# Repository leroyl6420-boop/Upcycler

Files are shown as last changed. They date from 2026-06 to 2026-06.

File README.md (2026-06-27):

# Upcycler
A machine that turns plastic PET bottles into 3D printing PET filament! 

This is the biggest project I have ever worked on as a middle schooler going into high school. I started this project to reduce plastic pollution, and also to stop wasting tons of money on filament for my voracious 3D printer! I'm making it open source, so you can replicate it (without spending months of time on mistakes!) 

Pros:
- Good for the environment!
- Costs only $50!
- Fun to make!

Cons:
- Threatens to put filament companies out of business!

I hope that my repo helps you replicate my proudest achivement yet! Have fun!

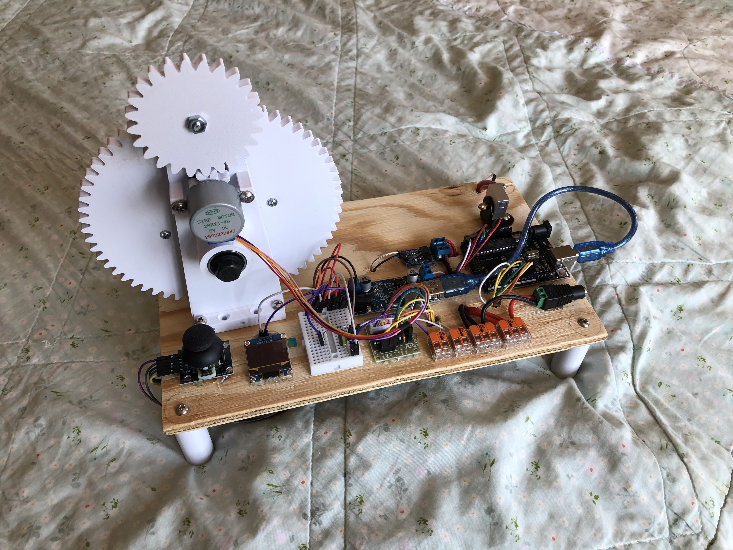
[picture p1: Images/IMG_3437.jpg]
Picture of Upcycler


The following are instructions on how to build the Upcycler yourself:

# PARTS TO PRINT

Print these parts however you like to print mechanical components! I like to print them fast with PLA (to save time and money), but print them out of CF if you want to pass your Upcycler onto your great-great grandchildren! The following prices are based of generic PLA prices.

- Main Body x1 (aprox. $0.92)
- Short Body x1 (aprox. $0.62)
- Spool Cap x1 (aprox. $.30)
- Leg x4 (aprox. $0.67)
- Big Gear x1 (aprox. $1.22)
- Small Gear x1 (aprox. $0.04)
- Driven Gear x1 (aprox. $0.23)
- Driver Gear x1 (aprox. $0.07)
- Spool Body x1 (aprox. $0.96)

# Physical Components

These are the parts you might have lying around if you have a 3D printer, or that you may find at Home Depot or Lowe's. Keep in mind that the prices are based off bulk prices I found in those stores. However, most of the pieces are very general-use (like the #6-32 and #8-32 screws) so I'm sure you'll find good use for them ;) 

- Base (cut a 0.3in thick piece of plywood into a 12in x 7in board) x1 (aprox. $1.80)
- Metal L-Bracket (make sure that the diameter of the holes are 6mm, not 5mm) x1 (aprox. $0.23)
- CR-10 Heat Block x1 (aprox $1.25)
- 1/16in Nozzle (use drill and 1/16in attachment to make your own out of any size) x1 (aprox. $0.50)
- #8-32 1.5in Screw x1 (aprox. $0.27)
- #8-32 1in Screw x4 (aprox. $0.40)
- #8-32 0.75in Screw x7 (aprox. $0.63)
- #6-32 1in Screw x8 (aprox. $0.64)
- #8-32 Hex Nut x5 (aprox. $0.45)
- 608 2RS Bearing x7 (aprox. $2.10)
- M8-1.25 60mm Half-Thread Screw x2 (aprox. $2.00)
- M8-1.25 Hex Nut x4 (aprox. $0.72)

# Electronic Components

Oh boy! These aren't parts you'd find walking around your local Micro Center! You may purchase them off your favorite online electronic retailer if you'd like, but if you prefer faster shipping (like me!), all these parts are available on Amazon! (Which is also what their prices are based on).

- ULN2003 x1 (comes with most 28BYJ-48 Stepper Motors)
- 28BYJ-48 Stepper Motor x1 (aprox. $3.00)
- Joystick (any cheap KY-023 clone will work fine) x1 (aprox. $1.67)
- 128x64 OLED x1 (aprox. $2.70)
- 12V 40W Ceramic Heater (get one that's meant for Creality Ender 3 printers) x1 (aprox. $1.40)
- Thermistor (get one that's meant for Creality Ender 3 printers) x1 (aprox. $0.80) 
- 12V-5V Buck Converter (I bought the B0FJM8XTSD, but any such converter that can handle 5A should work) x1 (aprox. $3.50)
- USB Type B (for Arduino Unos) x1 (comes with most Arduino Uno R3's)
- Arduino Uno R3 (I wouldn't buy the real thing, just buy a cheaper clone) x1 (aprox. $7.00)
- 2-Way WAGO x2 (aprox. $0.68)
- 3-Way WAGO x2 (aprox. $0.86)
- Small Breadboad x1 (aprox. $1.00)
- 50V 1uf Capacitor x1 (aprox. $0.40)
- 100k ohm Resistor x1 (aprox. $0.06)
- MTSD001 MOSFET Module x1 (aprox. $1.34)
- 12V 5A Power Supply (buy one that feeds through a jack, and make sure it comes with a female port to plug into that feeds wire connectors) x1 (aprox. $8.00)
- 16 AWG Wire (unspecified amount and cost)
- 22/24 AWG Jumper Wires (unspecified amount and cost)

All parts should run you about $48.43, pre-taxes. 

# Assembly Instructions

Now is the time to put everything together! I'll just go over the order in which you do things, and for attaching all electronic components to the base, just use hot glue and the general layout shown in the picture above.

- Drill 3/16in holes on each of the four corners of the base for the legs
- Screw legs in using #8-32 0.75in screws
- Insert all 7 bearings into all 7 bearing slots
- Insert M8-1.25 60mm screw into the main body's stud bearings: the cap should be on the protruding side
- Use M8-1.25 hex nut to secure said screw in place
- Screw Big Gear onto M8 screw
- Screw another M8 nut onto M8 screw to secure Big Gear in place
- Insert M8-1.25 60mm screw into short body's stud bearings (again, cap should be on protruding side)
- Use M8-1.25 hex nut to secure said screw in place
- Screw Spool Cap onto M8-1.25 screw
- Use M8-1.25 hex nut to secure Spool Cap in place
- Use four #6-32 screws to secure spool body onto the Big Gear
- Secure the Spool Cap (along with the short body) onto the other end of the spool body (using the other four #6-32 screws)
- Screw 2 #8-32 1in screws into the two outermost slots of each body's base
- Drill 4 3/16in holes into the base (two for the main body, two for the short body)
- Slide the two bodies into their slots, and on the belly side of the base, use four #8-32 nuts to secure the screws in place
- Drill a 3/16in hole for the L-Bracket
- Use a #8-32 0.75in screw and #8-32 hex nut to secure the L-Bracket on its hole
- Use the 1/16in nozzle to attach the CR-10 heat block onto the L-Bracket
- Secure the thermistor and the ceramic heater into the CR-10 Heat Block
- Use the USB type B to connect the 12V-5V Buck Converter's USB to the Arduino Uno's big port
- Use two #8-32 0.75in screws to secure the 28BYJ-48 stepper motor onto the main body (with its driver gear attachment attaced)
- Insert the small gear and the driven gear, back to back, into the main body's upper bearing slots. The driven gear goes on the protrusion side, and the small gear goes on the Big Gear side. Use the #8-32 1.5in screw (with a nut) to secure them tightly together, such that they can't spin independently. 

# Wiring Instructions

Alright, now is the time to really lock in. Read all the instructions carefully, because one mess-up WILL fry all your components faster than wanton wrappers in hot oil!

- Connect Arduino 5V and Arduino GND to a 5V and GND rail on the breadboard (duh). Then go ahead and connect all the Vcc's and GND's. You can't possibly screw that up. No components use 3.3V, and expand the rails if need be.
- Joystick VRx goes to Arduino A3
- Joystick VRy goes to Arduino A2
- Joystick SW goes to Arduino D4
- 128x64 OLED SCL goes to Arduino A5
- 128x64 OLED SDA goes to Arduino A4
- Connect each end of the thermistor to one of the two-way WAGO connectors. Then insert a jumper wire with a male end and a bare end into the other slot (for each). Of course, the bare end goes in the WAGO. One of the jumper wires goes straight to GND. The other one goes to its own rail. It will the called the thermistor rail.
- The 50V 1uf capacitor connects the thermistor rail and GND.
- The 100k ohm resistor connects the thermistor rail and the 5V rail.
- A jumper wire connects the thermistor rail and A0.
- Moving on from the thermistor, IN1-4 on the ULN2003 go to Arduino D11-8, respectively.
- MOSFET TRIG/PWM goes to Arduino D5. You may need to solder this connection.
- Use the two 3-way WAGOs and 12V 5A rails. One slot connects the rail to the 12V 5A power supply's wire slot attachment, the other connects the rail to the 12V-5V Buck Converter, and the last slot connects the rail to the MOSFET module. You should be able to figure out + and - in and out, as long as you have more than two brain cells.
- Connect the 12V 40W ceramic heater to MOSFET out(s). 

You have successfully built your very own Upcycler! Feed it 7mm PET plastic strips (around 0.4mm thick) and it'll give you filament to your heart's content!

AI use: I used ChatGPT in PREVIOUS VERSIONS of the Upcycler (versions 1 and 2) to code the Arduino, as I was less experienced in coding then. However, after attending Horizons Nexus (which was really fun!) I learned a lot more skillz and I coded the Upcycler V3 by myself! Well, I was already familiar with the GPT generated code, and I can't say that I didn't use some ideas from there, but I didn't copy/paste anything and you could basically call it learning at this point ;) anyway I don't think it counts as AI use.

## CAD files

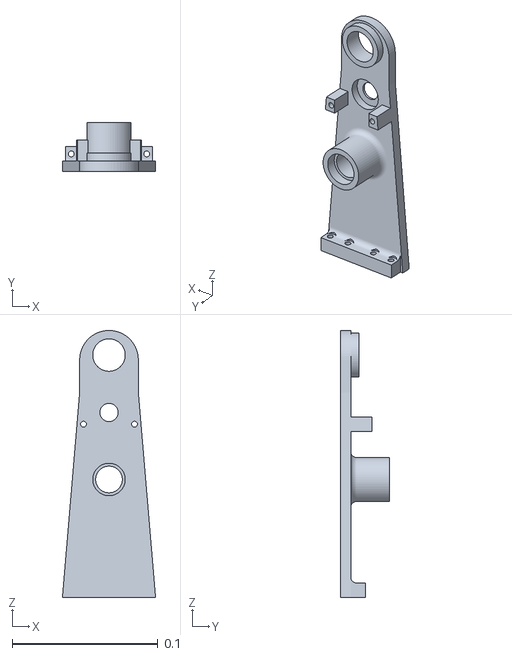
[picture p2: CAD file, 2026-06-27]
Parts to Print/Full Main Body (1).stl
0.064 x 0.0335 x 0.183

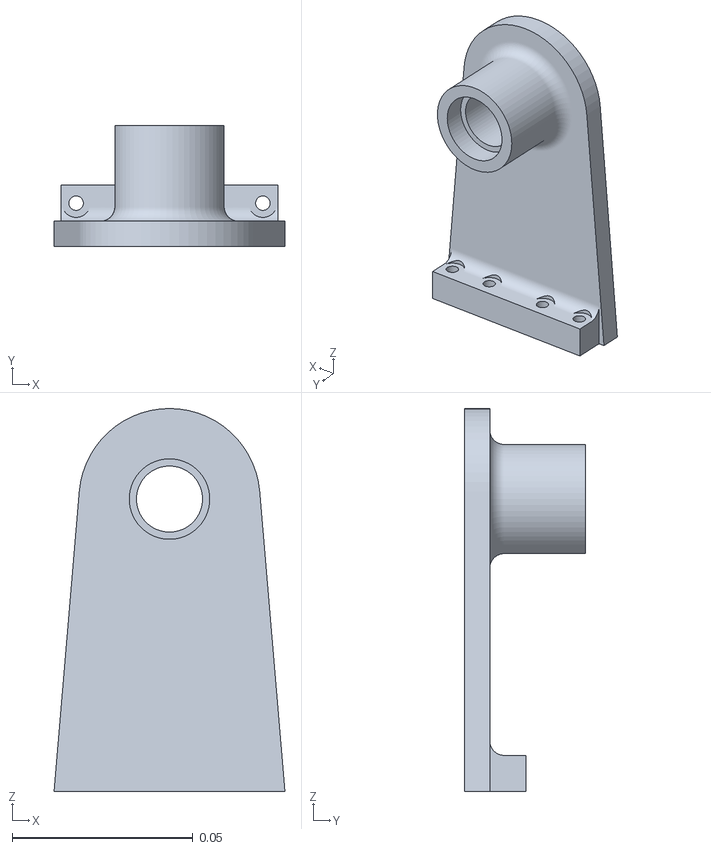
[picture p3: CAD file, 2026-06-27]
Parts to Print/Full Short Body (1).stl
0.064 x 0.0335 x 0.106

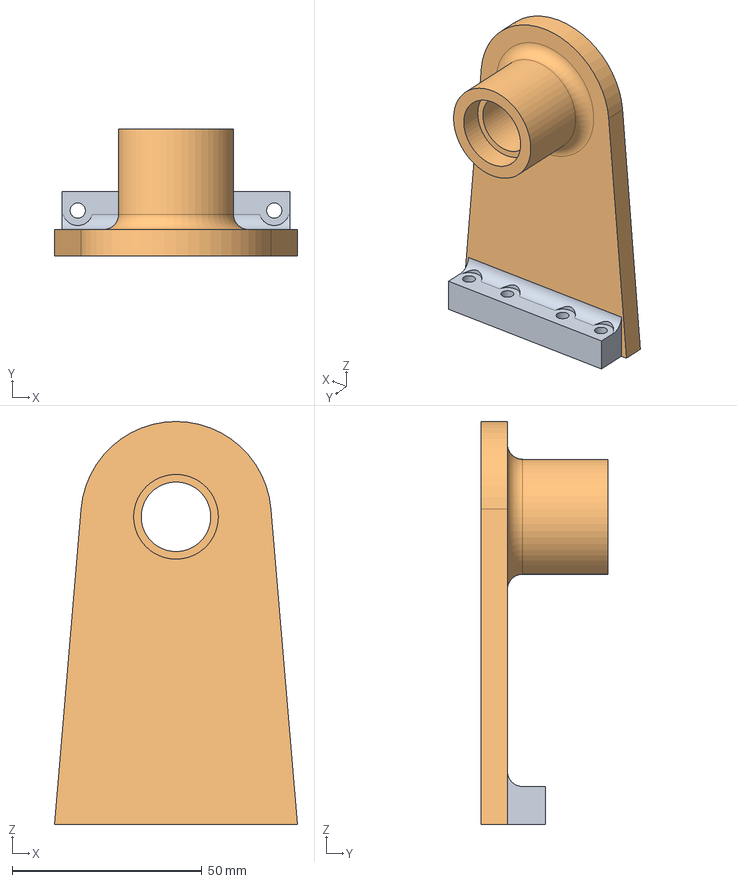
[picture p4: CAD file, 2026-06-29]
STEP Files/Full Short Body.step
64.0 x 33.5 x 106.1 mm
V2

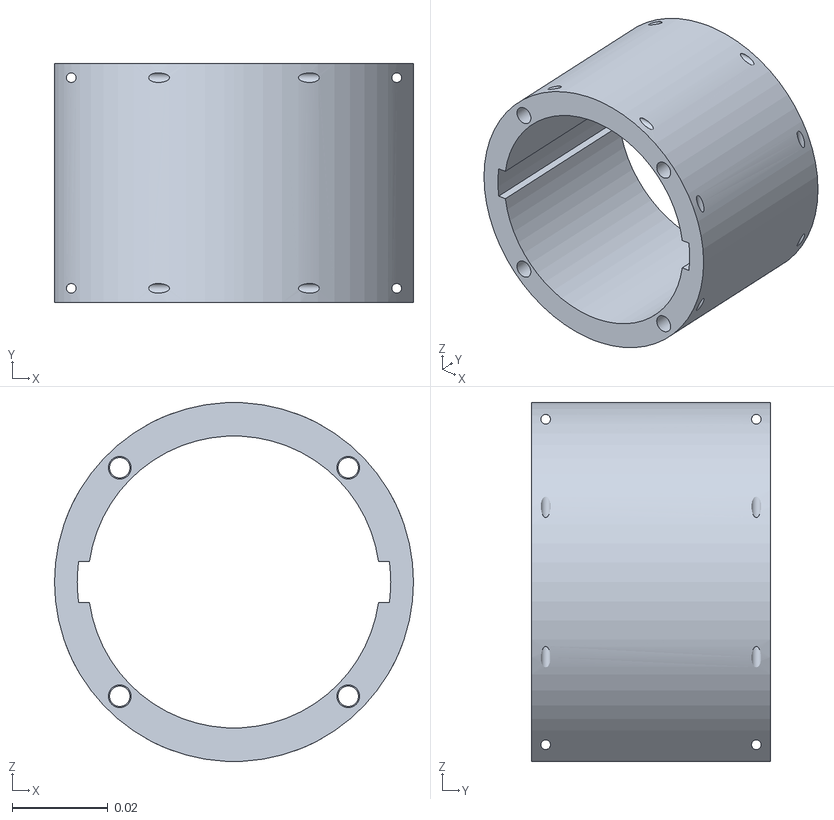
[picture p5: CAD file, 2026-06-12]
Parts to Print/PullerAssembly-SpoolSpoolBase (1) (3).stl
0.075 x 0.05 x 0.075

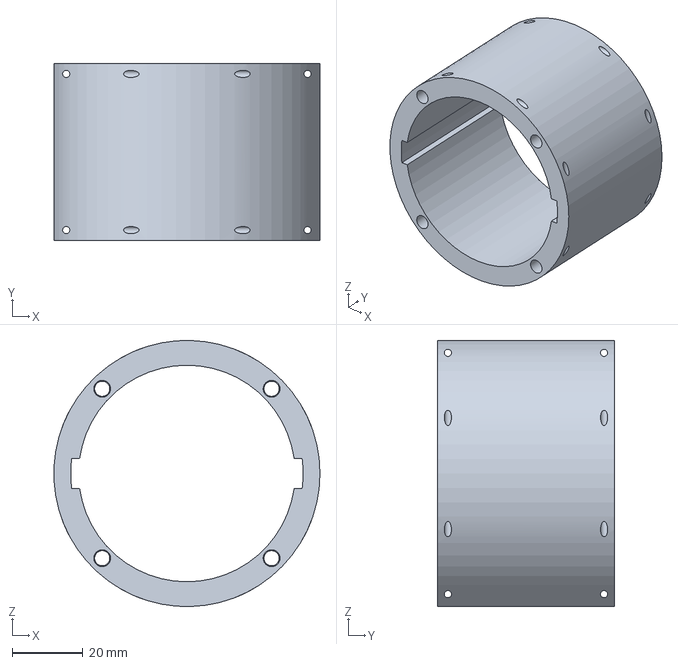
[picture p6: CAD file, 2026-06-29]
STEP Files/PullerAssembly-SpoolSpoolBase (1) (1).step
74.9 x 50.0 x 75.0 mm

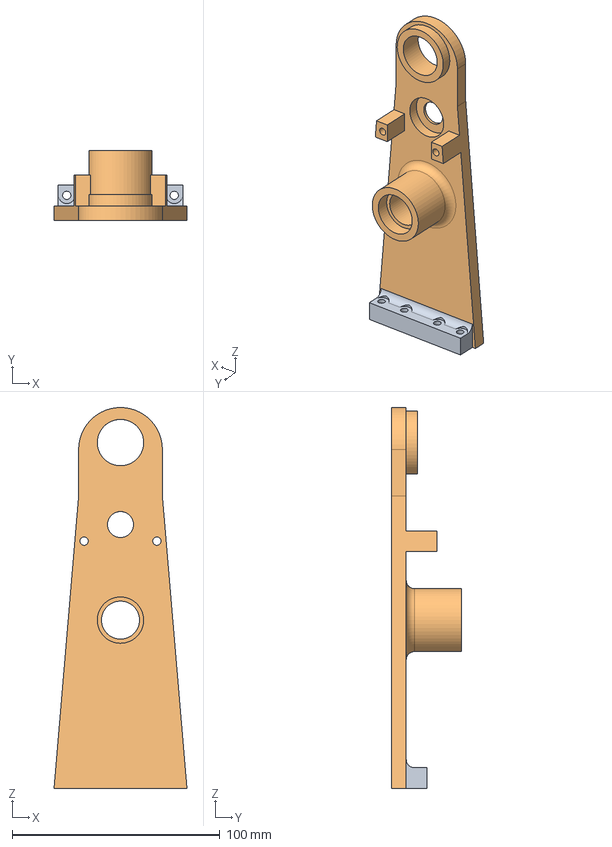
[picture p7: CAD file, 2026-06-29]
STEP Files/Full Main Body.step
64.0 x 33.5 x 183.3 mm
V2

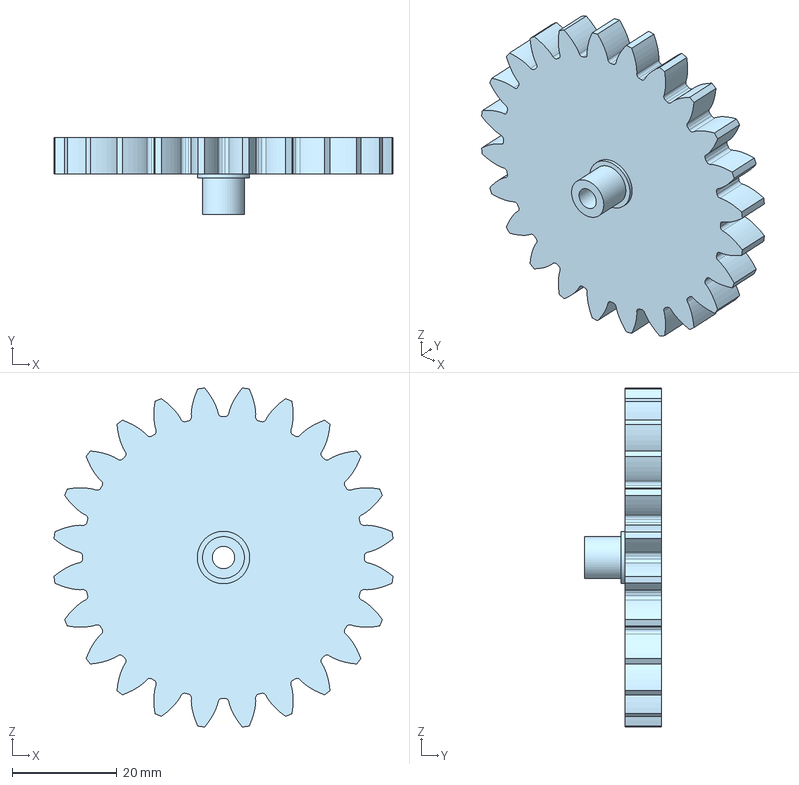
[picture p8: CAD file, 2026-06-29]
STEP Files/Driven Gear.step
64.6 x 14.7 x 64.6 mm

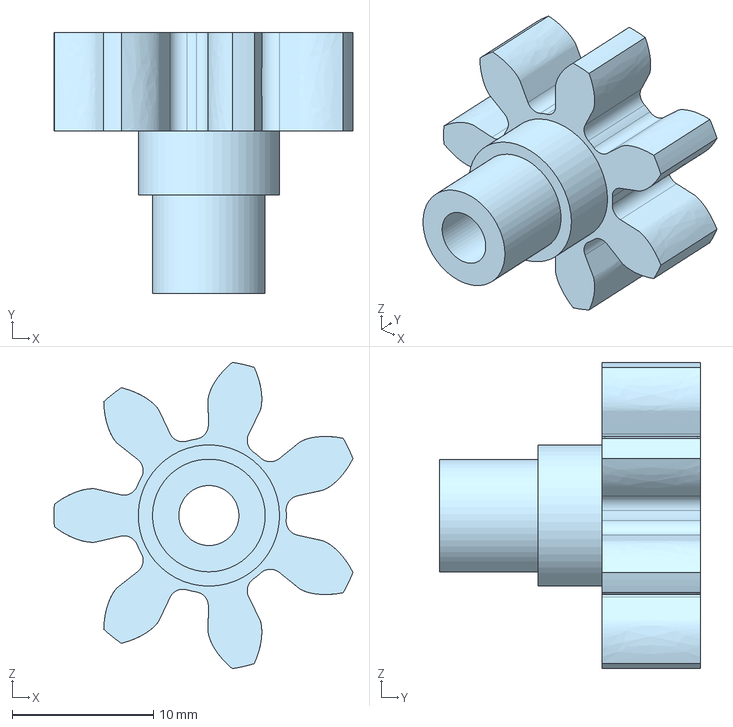
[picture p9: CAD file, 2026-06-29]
STEP Files/Small Gear.step
21.2 x 18.5 x 21.7 mm

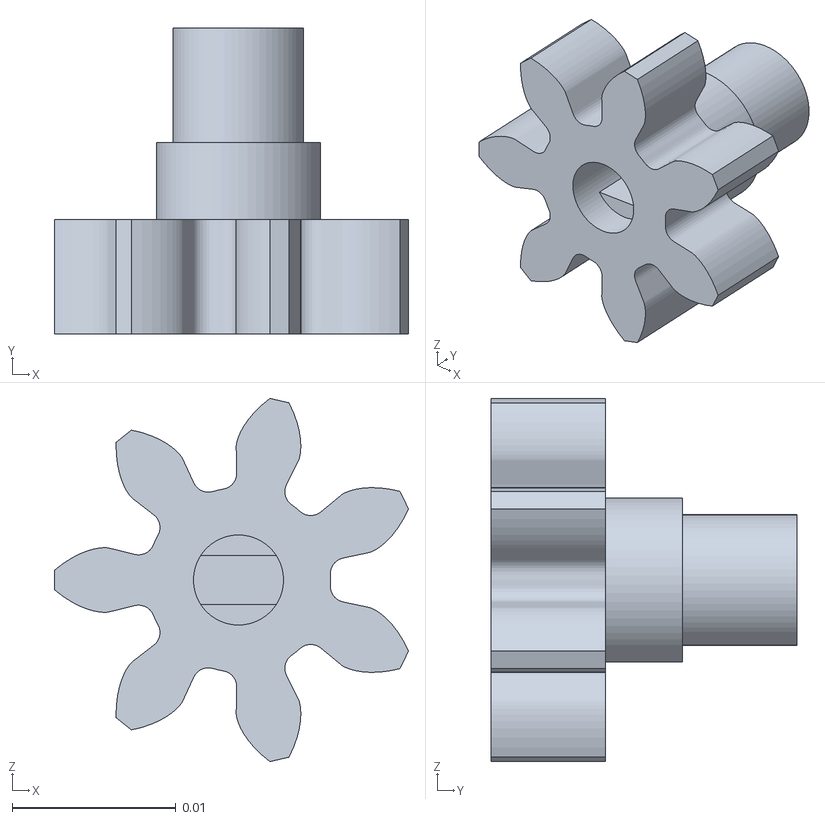
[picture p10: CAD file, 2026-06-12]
Parts to Print/Driver Gear (2).stl
0.0216 x 0.0187 x 0.0222

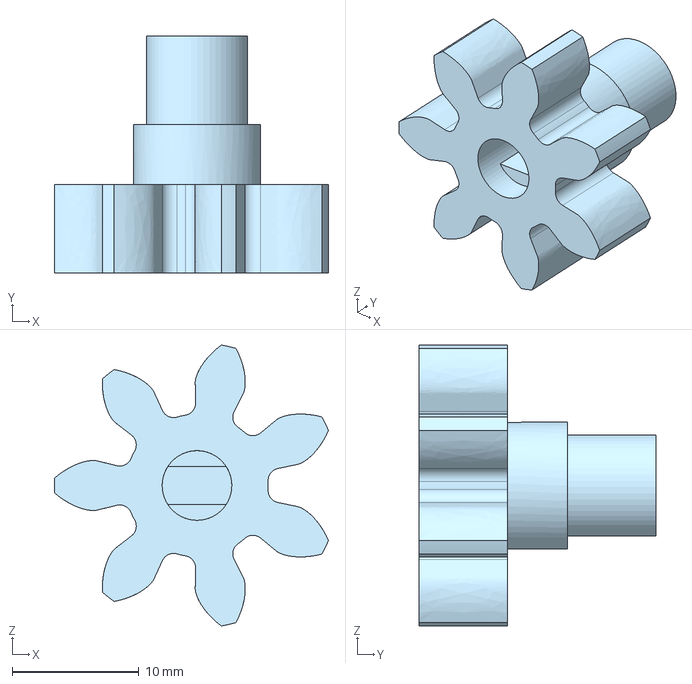
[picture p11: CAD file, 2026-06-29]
STEP Files/Driver Gear.step
21.6 x 18.7 x 22.2 mm

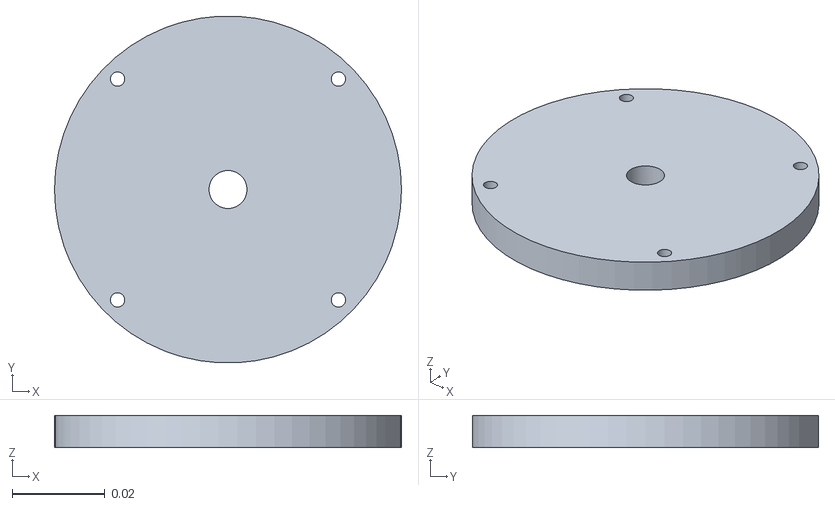
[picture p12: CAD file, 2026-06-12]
Parts to Print/Spool Cap.stl
0.075 x 0.0749 x 0.007

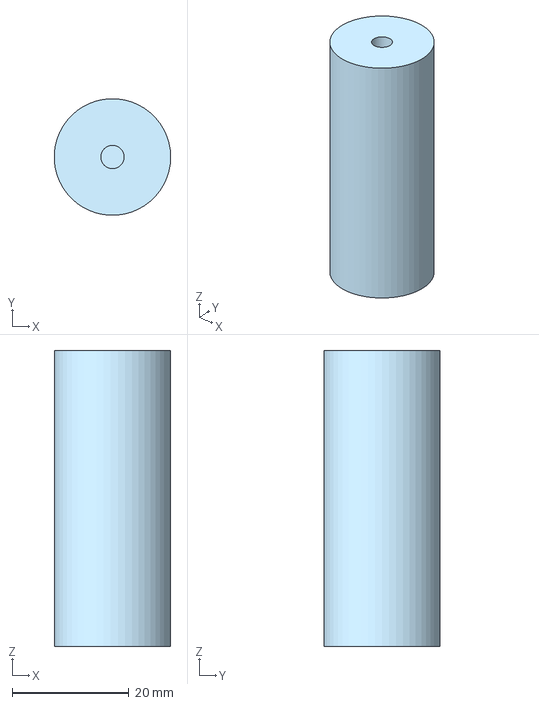
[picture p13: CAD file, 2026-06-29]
STEP Files/Leg.step
20.0 x 20.0 x 50.8 mm

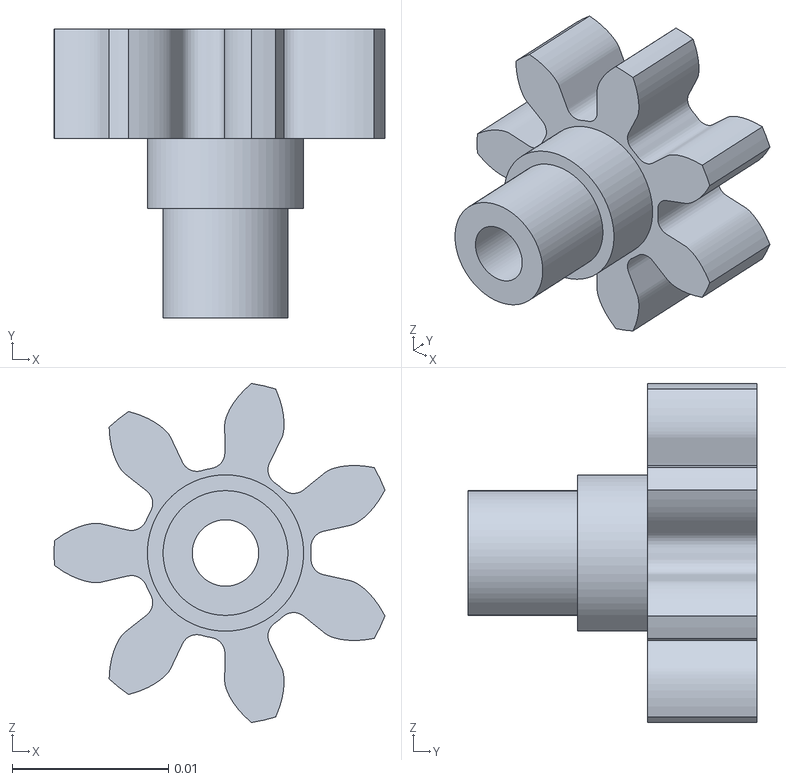
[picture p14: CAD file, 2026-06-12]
Parts to Print/Small Gear (6).stl
0.0212 x 0.0185 x 0.0217

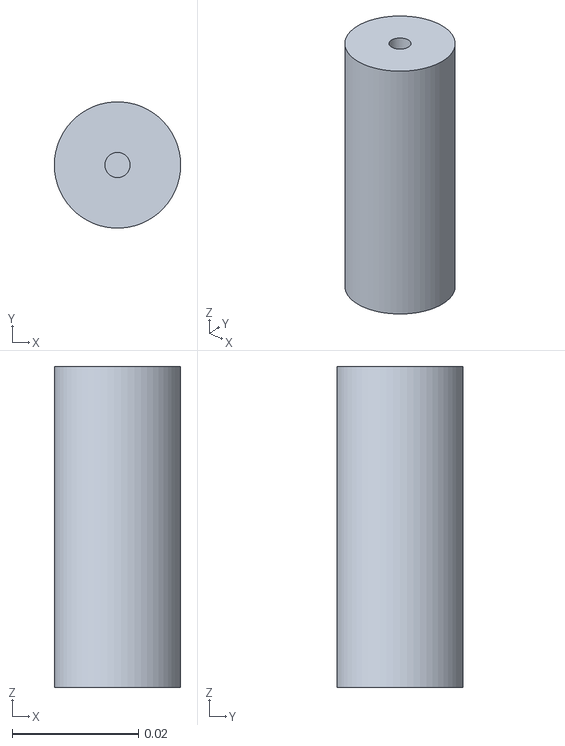
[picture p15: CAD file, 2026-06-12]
Parts to Print/Leg (1).stl
0.02 x 0.02 x 0.0508

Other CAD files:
Parts to Print/Big Gear (8).stl
STEP Files/Big Gear Inner Ring.step
Parts to Print/Driven Gear (2).stl
STEP Files/Big Gear.step

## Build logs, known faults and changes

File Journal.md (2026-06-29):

# Devlogs

Hi! Welcome to my project journal! Before you take a peek, you may realize that the commits do not match the logs. That is because this is literally my first time using Github and I didn't really know how to do a journal for devlogs until I was gonna ship :P
If you're a reviewer reviewing my project and you really need proof of the devlogs, I wrote quick summaries under each of my timelapses in Lapse, which is also what my devlogs will be based on. If you need anything from me to clear things up, please let me know in any way. I check Slack very often. Sorry for the inconvenience! Thank you for all your hard work :)

NOTE: If you are checking my project out from Stardance, the reason why I have this Journal.md is because this project was started in Horizons. I had to keep my devlogs here because there was no devlog feature on the website. I stopped updating this journal when I moved over to Stardance, and I wrote the rest of my devlogs there. Thanks for the understanding!

# Devlog 1
1h 0min 27sec Logged

I started working on my Upcycler project today! I need to make a full 3D model as a plan, so I found some files online of a motorized mechanism that pulls the PET in a PET puller. I imported them into my project, but I discovered that they need 608 2RS bearings, M8-1.25 60mm screws, and M8-1.25 hex nuts to be fully put together. I found the dimensions of those parts online and modeled them myself! Afterwards, I brought all the part studios into an assembly and put together the first model of the body (you can find models in branch First-CADS). However, I still need to greatly adapt the puller mechanism to use 28BYJ-48 stepper motors instead of expensive 12V 3RPM DC motors. I started that today by calculating the grams of force per centimeter sqaured of each motor. My motor was approximately 20x weaker than theirs. To compensate for friction, bending of the materials, and the fact that the spool's axle has only one attachment point, I estimated the need for a 30:1 ratio. I modeled the driven gear as large as I could, but my math still does not see my mechansim working. I'll need to improvise a geartrain for everything to work. 

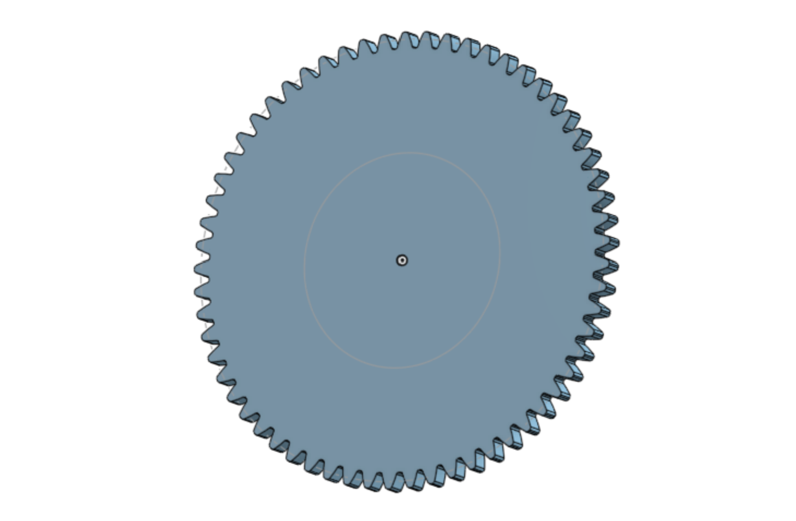
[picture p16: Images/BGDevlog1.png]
Picture of Big Gear

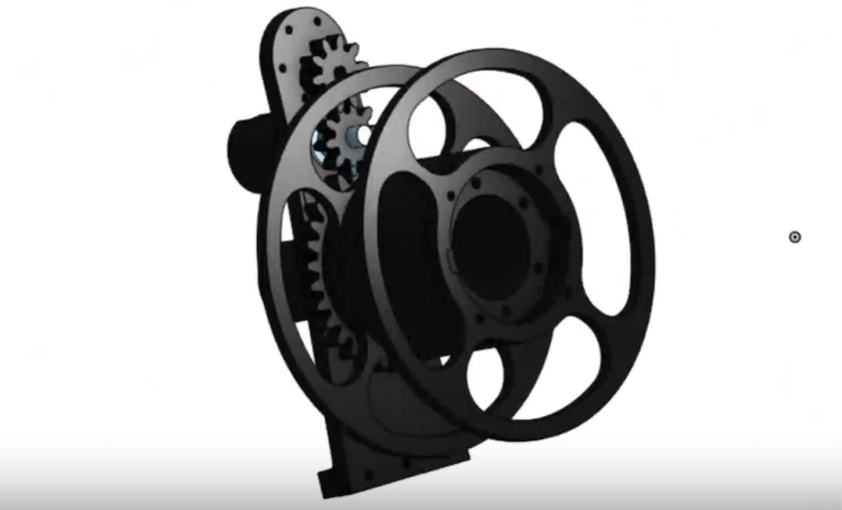
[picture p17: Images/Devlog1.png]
Picture of Upcycler
 

# Devlog 2
1h 1min 12sec Logged

I worked on the geartrain for my Upcycler! I finished modeling the big gear to fit the spool and the axle, and I'm getting started on the other gears. I've decided to incorporate four gears: the driver gear will be connected to the 28BYJ-48 stepper motor, the driven gear will be above that (at a 24:7 ratio), and the driven gear will be on the same axle the small gear, which will drive the big gear (at a 61:7 ratio). That should result it a roughly 30:1 ratio. Of course, to fit the new axles and gears, I had to change the body of the puller a lot. I removed the mounting holes meant for the original motor, and I made new slots for new bearings. You can find the files in the 2nd-CADs branch.

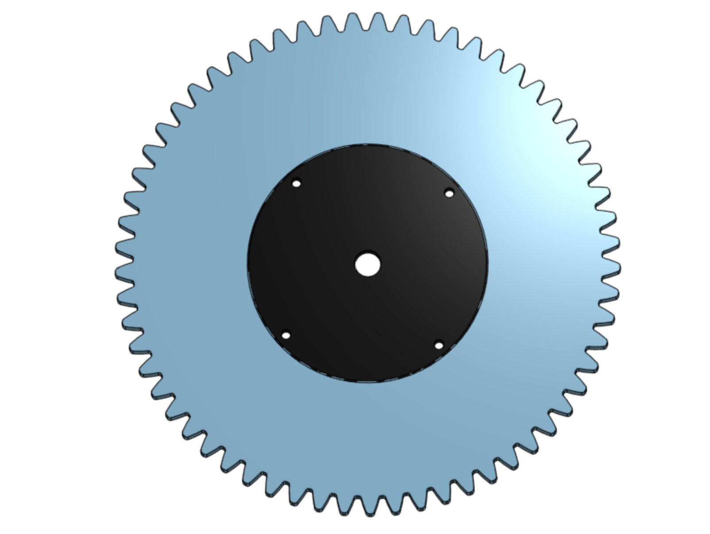
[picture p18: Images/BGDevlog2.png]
Another Picture of Big Gear
 
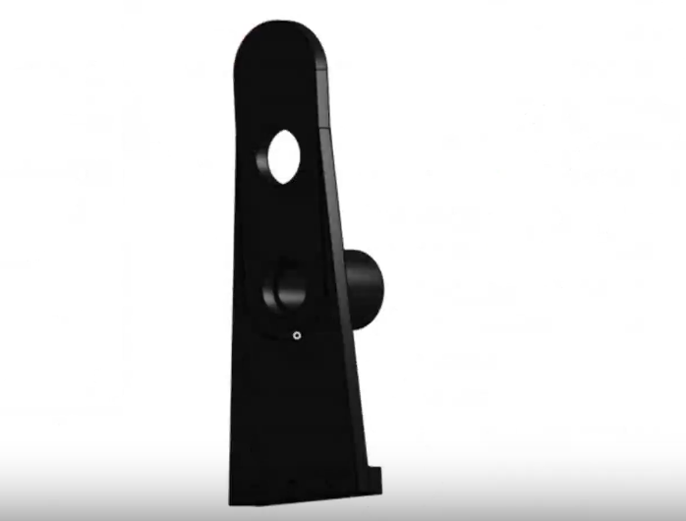
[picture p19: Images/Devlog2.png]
Second Picture of Upcycler
 

# Devlog 3
1h 4min 57sec Logged

I finished adapting the body of the puller! I added all the necessary bearing slots, I added attachment points for the 28BYJ-48 stepper, and I trimmed a bit off the stud to save filament, save time, and make installment easier. I modeled all three other gears, and I'll put the assembly together soon. however, I decided that I wanted two attachment points for the spool's axle. First, I had to make the other end of the spool capable of taking an axle. I modeled a spool cap by using the same inner ring I used for the big gear. I will be able to add that to the other end of the printed spool. That means I'll need to model a shorter body next, as the second attachment point doesn't need a motor and geartrain, but it does need support. 

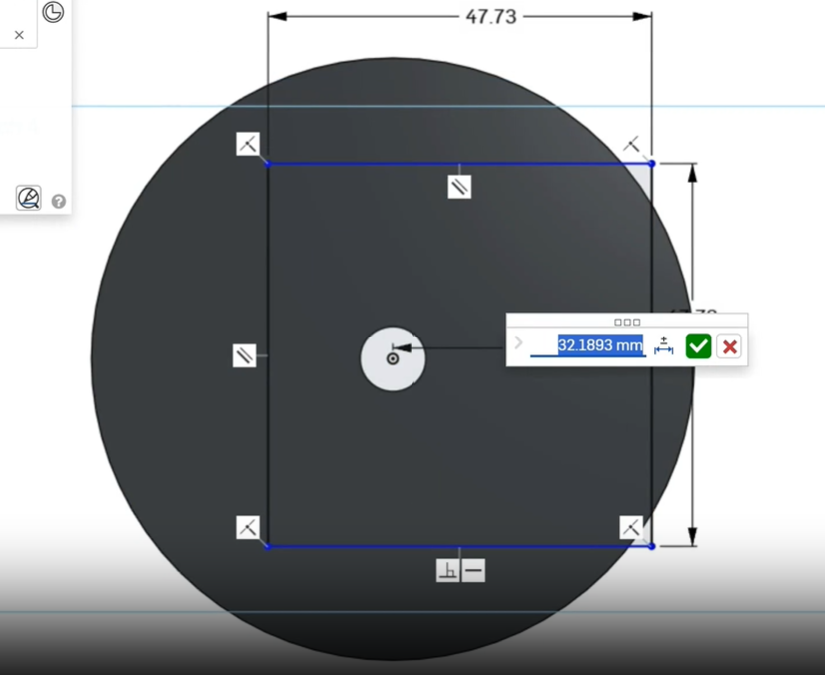
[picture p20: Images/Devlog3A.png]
Picture of Spool Cap

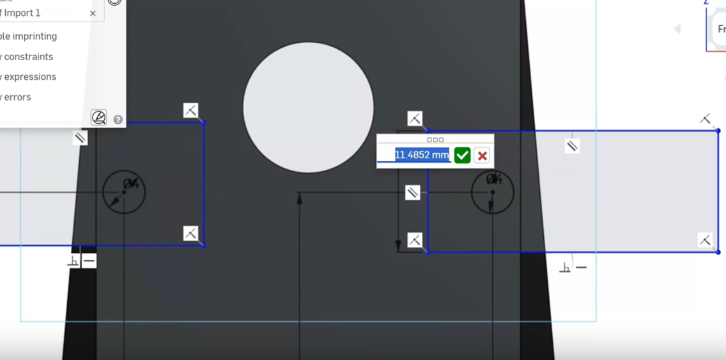
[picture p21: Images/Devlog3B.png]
Picture of adapted body


# Devlog 4
1h 7min 10sec Logged

First, I modeled the short body. I basically just copied the normal body and cut off the top. I used a circle centered on the axle and tangent to the body's sides to mark the roof. Afterwards, I modeled the legs of the Upcycler. I had to match dimensions I estimated in real life. I'm planning to secure them to the wooden base using #8-32 screws. Finally, I started putting everything together in the assembly again. So much has changed since I did this the first time! I had to redo a bunch of stuff. Everything fits perfectly, as per my calculations! I need to move on to modeling the rest of the Upcycler next: the puller is just one of the biggest parts. You can find the CAD files in the 3rd-CADs branch. 

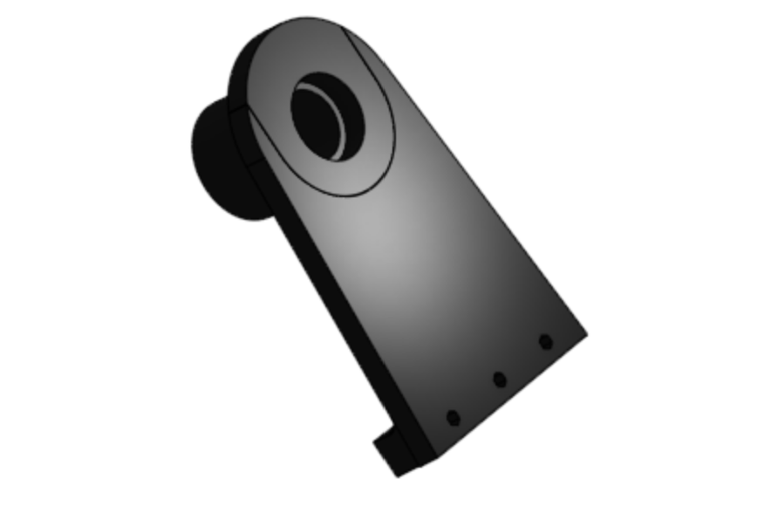
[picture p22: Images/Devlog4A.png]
Picture of short body

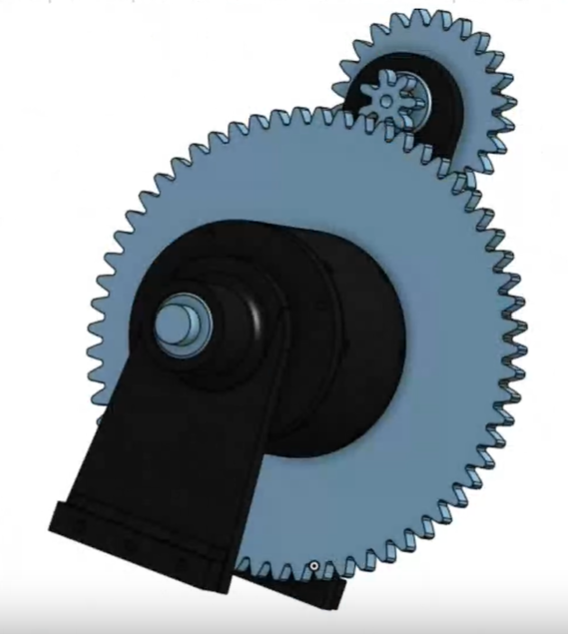
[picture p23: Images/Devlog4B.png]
Picture of Devlog 4 Assembly


# Devlog 5
1h 2min 49sec Logged

I grinded out models of all the screws that I'll be using! I couldn't find any #8-32 screw models online that were in parasolid format, so I decided to model them myself! I modeled the #8-32 1.5in, 1in, and 0.75in screws. I also modeled a 1in #6-32 screw. I added them all to the assembly and put them all in place! Afterwards, I added the base to the assembly and added holes to it for the #8-32 screws to secure the legs. Things are really coming together!

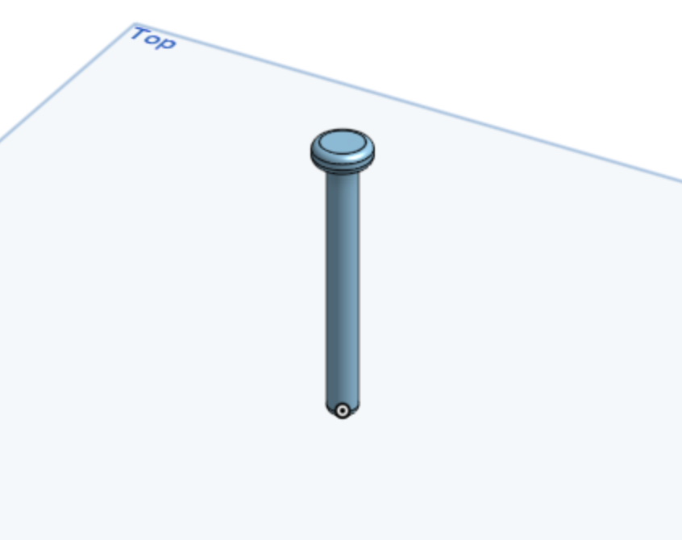
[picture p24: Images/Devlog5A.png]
Picture of #8-32 1.5in screw model

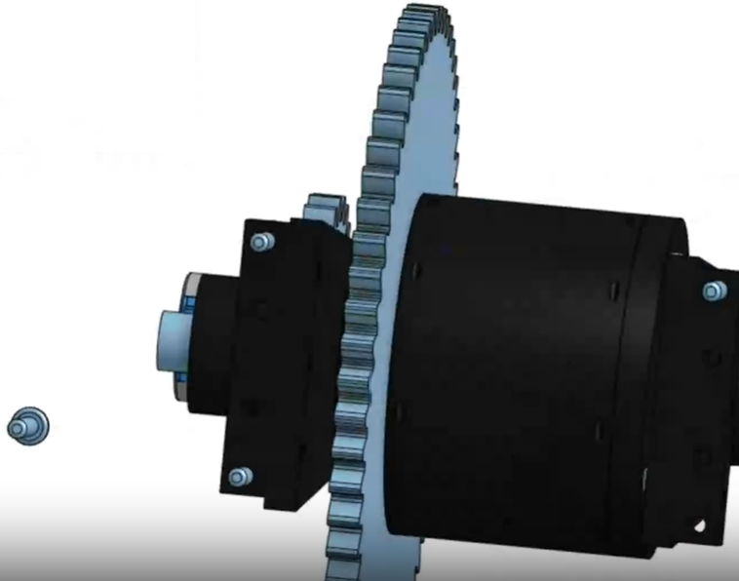
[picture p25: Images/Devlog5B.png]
Picture of assembly with screws


# Devlog 6
1h 4min 45sec Logged

I added more holes to the base for attaching the puller. The plan is to make the holes around 3/16in wide in diameter in real life, larger than the #8-32 1in screws' diameters, so that there will be room for error while drilling. Then, the screws (and the bodies they wil be securing) will be secured using #8-32 hex nuts. I added the legs to the assembly and attached them to the base as planned. Finally, I found 3D models of a few of the electrical components I used online and added them to the assembly. I don't like them very much, as they are not parasoilds that Onshape can render easily, but I suppose they'll do for now. I think I'll just make my own models in the future. 

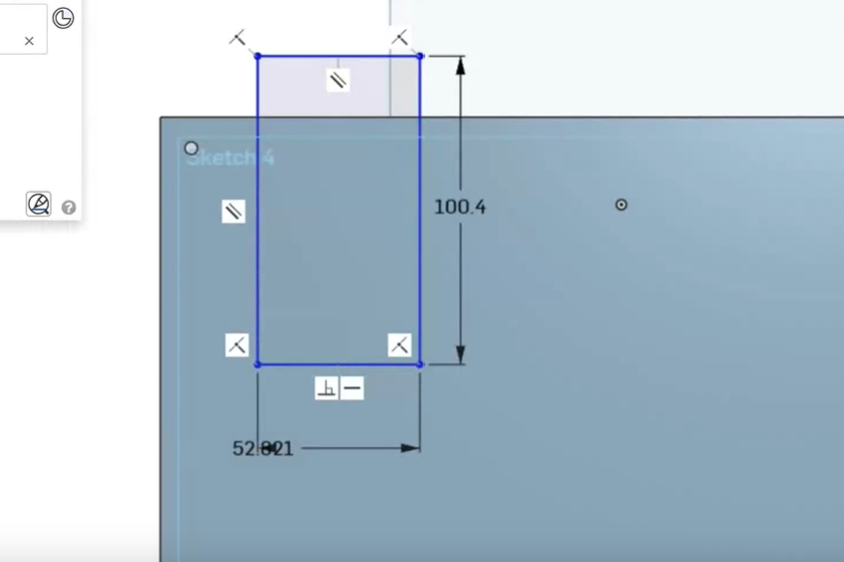
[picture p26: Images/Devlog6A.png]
A picture of adding holes to the base

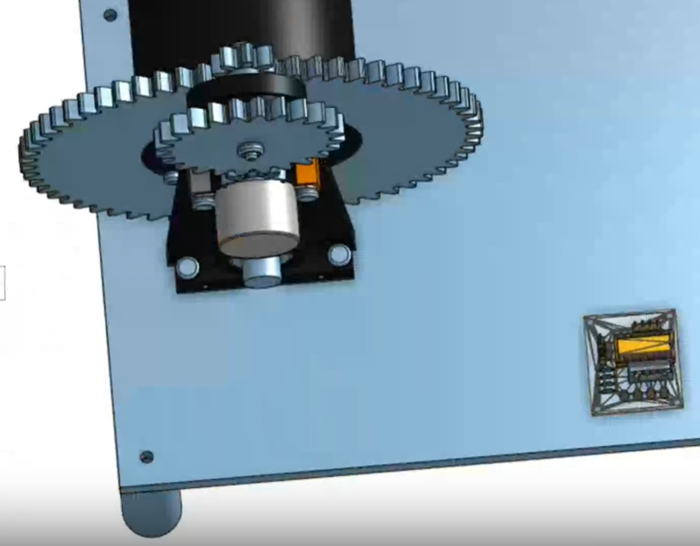
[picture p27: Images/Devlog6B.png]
A picture of the assembly with legs and an imported ULN2003 model


# Devlog 7
1h 0min 22sec Logged 

I found more files for more of the electronics I used online. One of them, the breadboard, was able to be rendered by Onshape, and it looks fine. The other, the OLED, was not able to be rendered by Onshape, and it is another janky-looking part. I still added them to the assembly. I wanted to add the WAGOs next, but I also wanted to avoid weird files, so I modeled the WAGOs myself. I found the dimensions online and even added fillets to make them look more realistic. I think that I'm pretty good at that, so I think I'll model more parts. In the meantime, the assembly is looking more and more complete every Devlog! You can find the files in the 4th-CADs branch. 

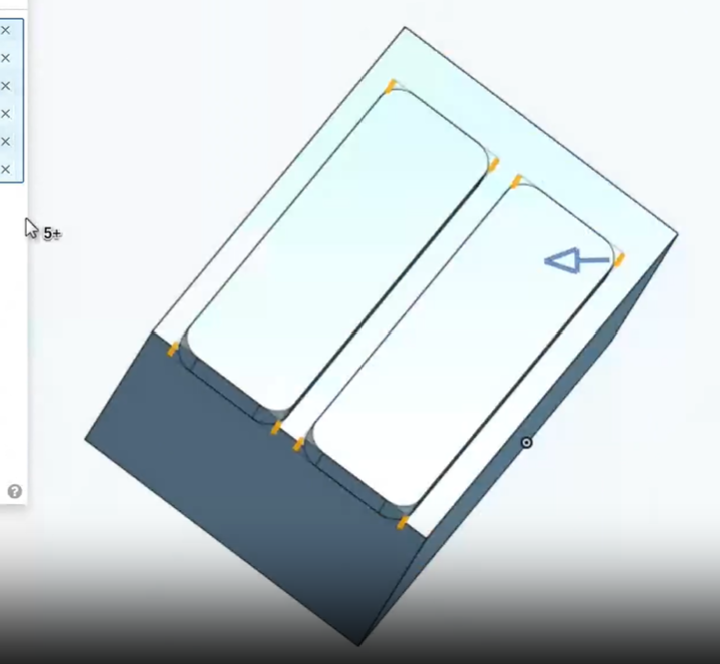
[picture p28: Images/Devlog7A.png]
A picture of a 2-way WAGO I modeled

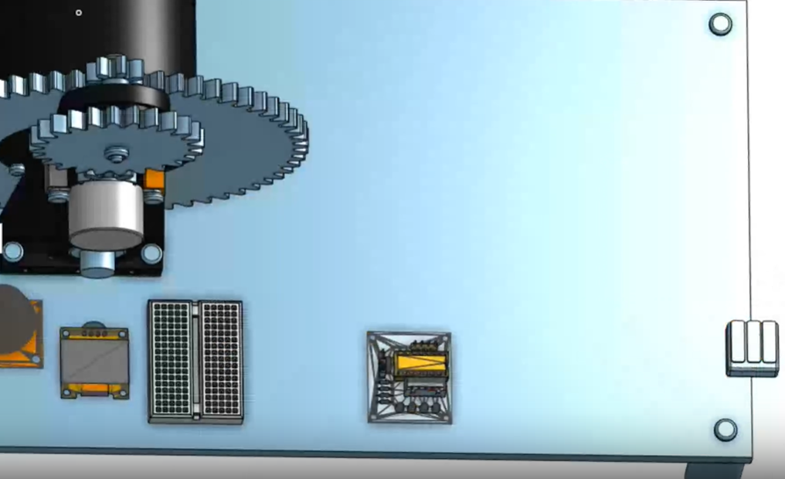
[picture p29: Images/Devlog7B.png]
A picture of the assembly with all the parts thus far


# Devlog 8
2h 53min 17sec Logged 

Oh, boy! I really locked in for this CAD session! I modeled the rest of the components, by myself!I modeled the relay, the 12V-5V buck converter, the l-bracket, the CR-10 heat block, and I turned the assembly into a simulation! The l-bracket and CR-10 heat block were easy to model, because I just had search up their dimensions online and translate that into a part studio in Onshape. The relay and 12V-5V buck converter were harder. I had them in real life, so I used a digital caliper to measure the individual parts and model them in Onshape to the best of my ability. I got details like filets and chamfers, and I added extrude removes for USB ports, wire ports, and screw ports. Afterwards, I added all the parts to the assembly, and I finished putting everything together! That wasn't it, though! To see how it would really work, I added gear relationships to the revolve mates of the gears, and I saw Onshape simulating the Upcycler running! I'm ready to build the Upcycler now!

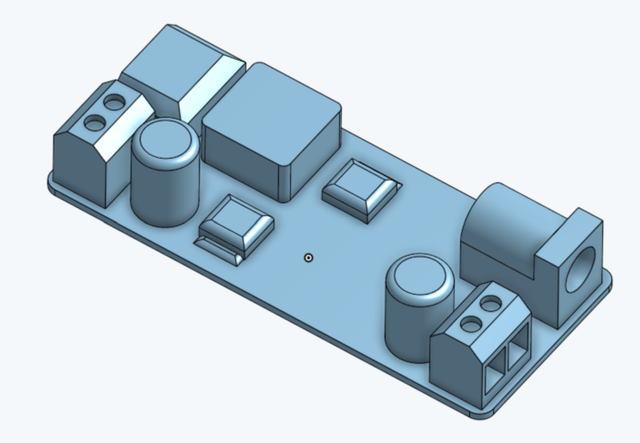
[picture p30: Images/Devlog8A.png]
A picture of the 12V-5V buck Converter

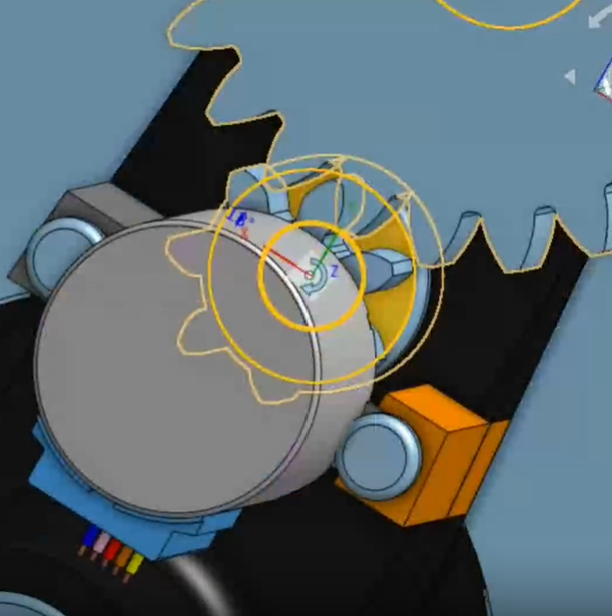
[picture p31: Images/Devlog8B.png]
A picture of adding simulation to the gears

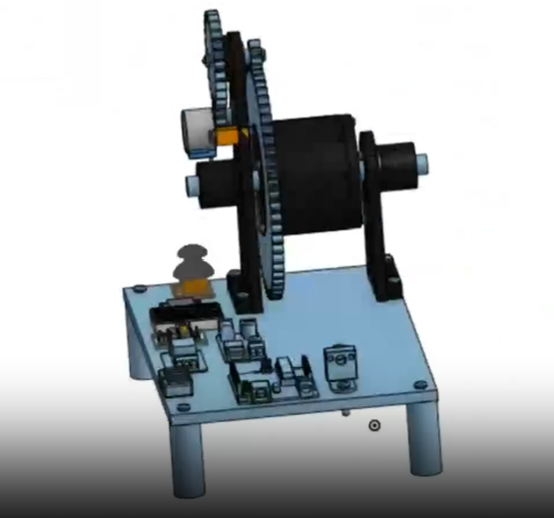
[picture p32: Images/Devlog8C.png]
A picture of the finished assembly


# Devlog 9
1h 2min 34sec Logged

This was my first building session! First, I drilled four holes at the corners of the wooden base I got to attach the legs. I had printed the legs out beforehand, so I just had to screw them on. Then, I put together the short body. I inserted the bearings, I threaded the M8-1.25 60mm screw, I screwed on a nut, I screwed on the spool cap, and I screwed on a second nut. Afterwards, I put together the axle of the main body. I repeated the same process as the short body, but I used the big gear instead of the spool cap. I then secured the spool body onto the big gear using four #6-32 1in screws. Things are going well so far!

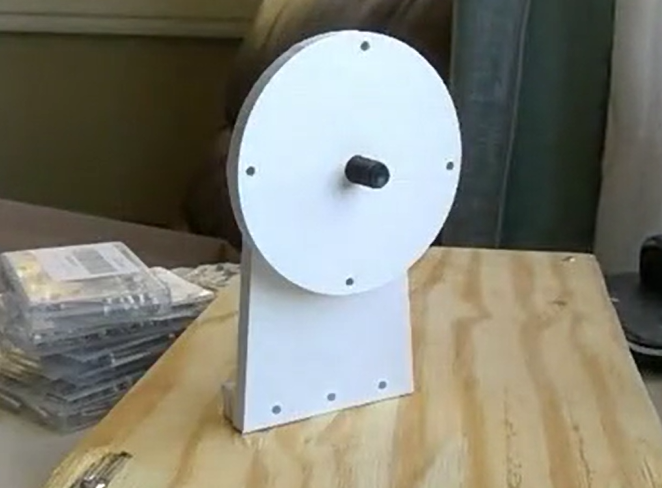
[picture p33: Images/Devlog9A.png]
A picture of the assembled short body, short of the second nut

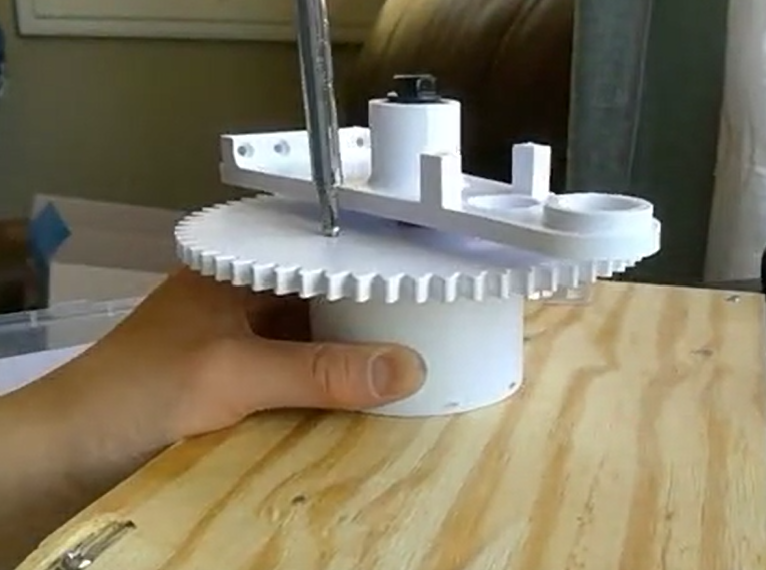
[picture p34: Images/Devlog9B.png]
A picture of securing the spool body to the big gear on the main body


# Devlog 10
1h 6min 37sec Logged

I continued building the Upcycler! I screwed the driven gear and the small gear together using a #8-32 1.5in screw, and after attaching a nut, they can no longer spin independently. However, that was before I screwed the base screws onto the body, and the driven gear got in the way of me doing that, so I had to undo my work, screw in the base screws, and put them back on again. In other news, I attached the spool cap (and the short body) onto the other side of the spool body, making our puller assembly complete! Our 28BYJ-48 stepper motor is ready to go, it just needs the electrical components now, which is what we will be working on next!

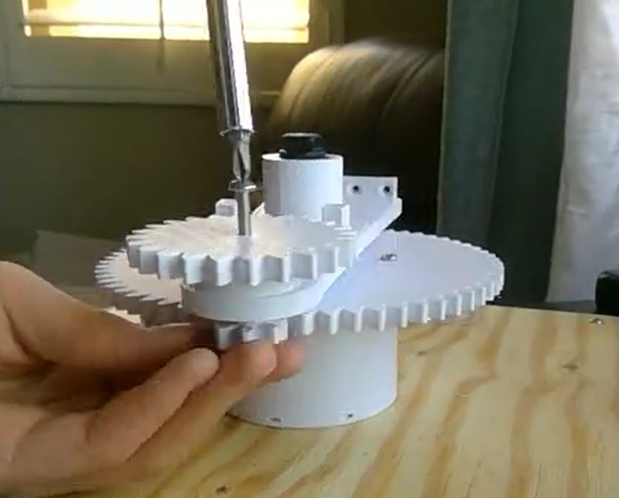
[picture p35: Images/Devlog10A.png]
A picture of me joining the driven gear and the small gear using a #8-32 1.5in screw

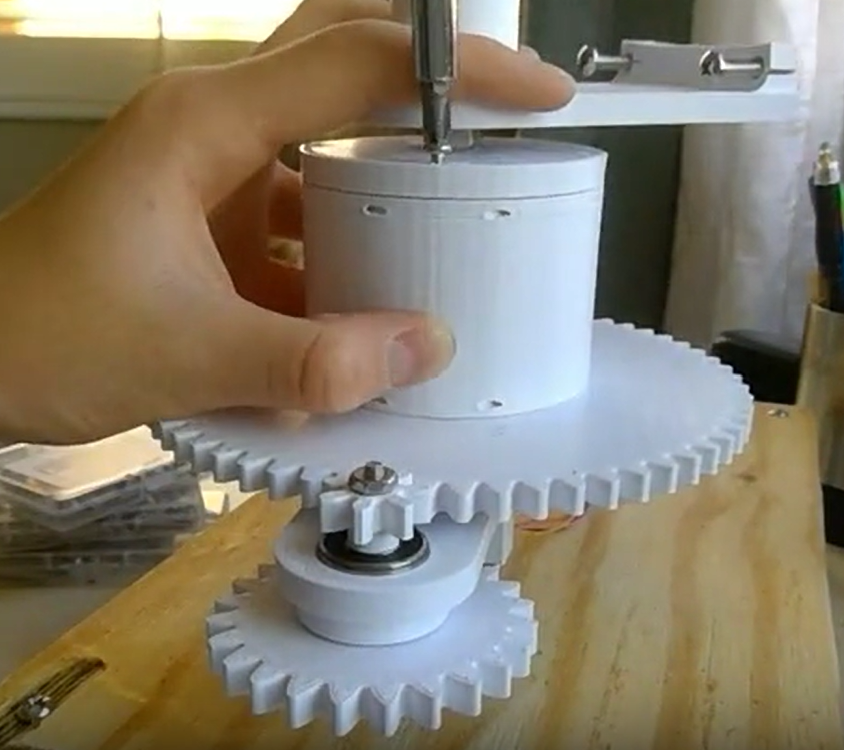
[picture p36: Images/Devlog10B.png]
A picture of me attaching the spool cap and the short body onto the other end of the spool body


# Devlog 11
1h 45min 52sec Logged

I finsihed building the Upcycler's electrical system today! I drilled the holes in the base for the bodies of the puller assembly, and I slid the bodies into the holes via their screws. On the belly side of the base, I used #8-32 hex nuts to secure the bodies in place. I hot-glued all of the elecrical components in place, and I got all of the wiring done, shy of the heat block. The heating component is the last part I need to finish. In other news, I found the relay I wanted to use too big, so I replaced it with a MOSFET module. I'll redo the CAD on that part next. 

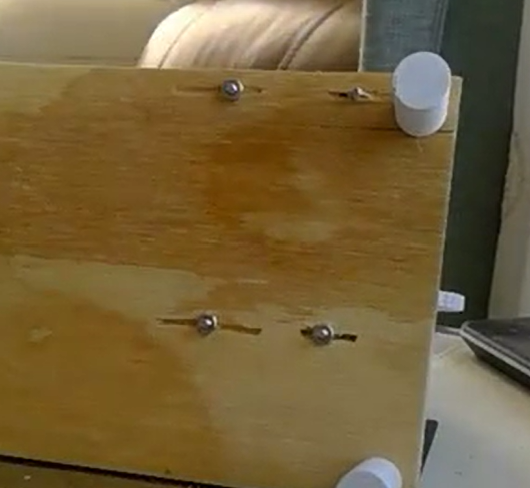
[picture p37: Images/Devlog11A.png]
A picture of the underside of the Upcycler, with 3 of the 4 hex nuts installed for the screws of the bodies

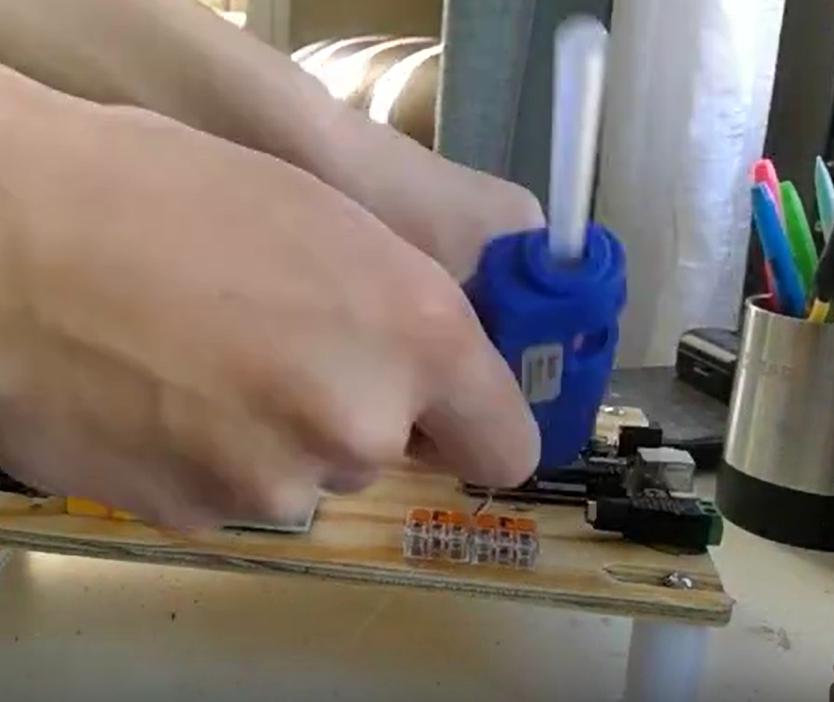
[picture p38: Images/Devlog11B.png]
A picture of me hot-gluing the Arduino Uno in place

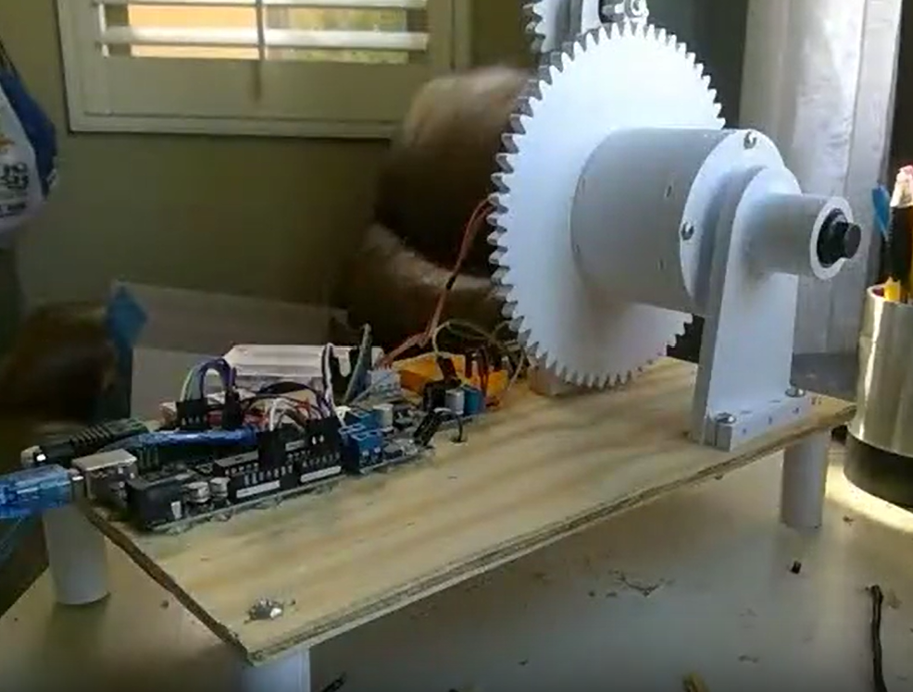
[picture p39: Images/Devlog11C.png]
A picture of the up-to-date Upcycler!


# Devlog 12
0h 37min 57sec Logged

I updated the assembly to have the MOSFET module instead of the relay! I modeled the MOSFET that I used, and I used it to replace the relay in the assembly. This fit a lot easier now. The updated CAD files are in 6th-CADs (branch).

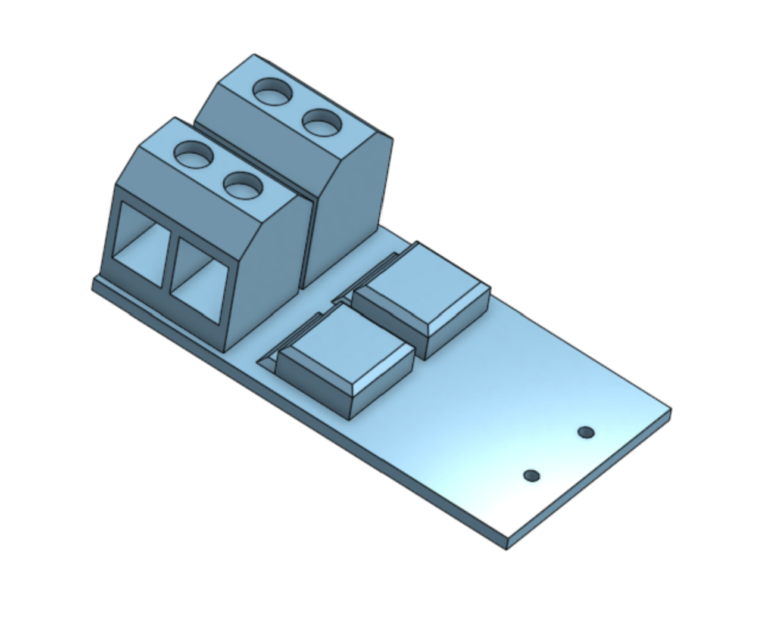
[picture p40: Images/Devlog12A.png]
A picture of the MOSFET module I modeled

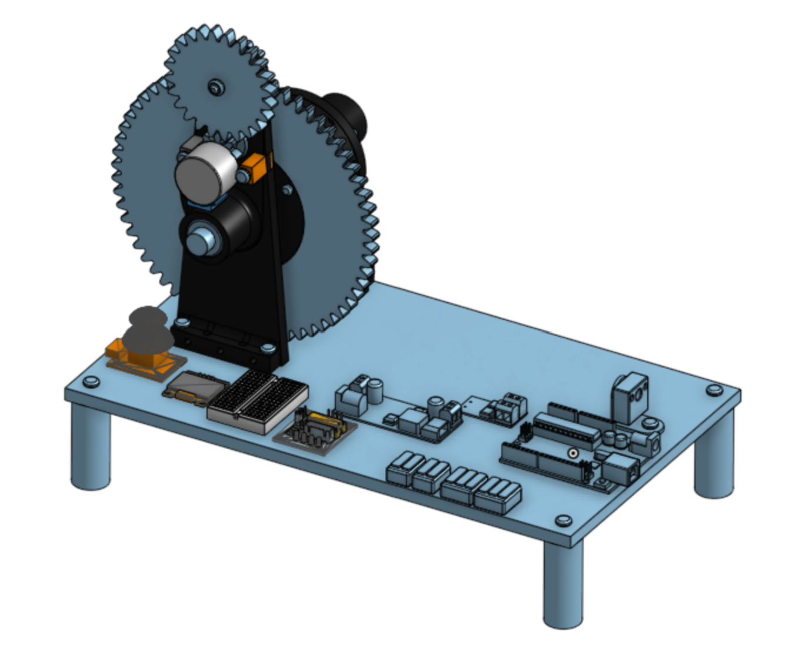
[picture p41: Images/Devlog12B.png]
A picture of the up-to-date CAD assembly


# Devlog 13
49min 20sec Logged

Hi! This is the first devlog for my Upcycler project on Stardance! I started this project in Horizons, but I decided to move over to Stardance after 15 hours of work after seeing how Stardance is more hardware-oriented. To recap the work I did in Horizons, I found a set of 3D files for a body of a Petamentor and adapted them to use a 28BYJ-48 stepper motor. I chose a lot of parts to heat up 7mm strips of PET and control the motor, modeled them on Onshape, bought them in real life, and assembled part of the Upcycler. For this first devlog in Stardance, I started assembling the heating component. I drilled holes in the base to fit the L-bracket that will hold the heat block, and I attached two two-way WAGOs to incorporate a thermistor to track the temperature of the heat block. I added all of the electrical components the thermistor will need. Of course, there is a lot more to my journey than I wrote here. Check out my Github repo to see the entire process (including my work in Horizons!)

A picture of the in-progress Upcycler

# Devlog 14
38min Logged 

I finished building the heating component for the Upcycler today! I connected the ceramic heater to the MOSFET module, and I inserted both the heater and the thermistor into the heat block. I secured the heat block onto the L-Bracket using an adapted 0.4mm nozzle (I expanded it to 1/16in). The entire physical build for the Upcycler is complete! I will work on an improved code now!

A picture of the completed Upcycler V2

# Devlog 15
1h 19min 45sec Logged

I finished updating the code for my Upcycler project! I already knew the jist of the things I needed from the AI-generated code I used to use, so I was able to finish everything in just one session.
The biggest change I made was adding a safety feature for the heating component. If the 6x20mm 12V 40W ceramic heating components I use get too hot, they pose a fire hazard, not to mention the fact that they can damage themselves, the parts around them, and the electrical components they connect to. They can only go up to 350 degrees Celsius before those things start to happen, and my old code allowed operation up to 360 degrees, so I updated the max to be 340 (meaning there’s a 10 degree margin of safety).

I also made a few quality of life changes in the UI.

I listed the current code version and model next to the title
I labeled the temperature readings in both the main menu and the operating menu with “C” (to clarify that the readings are in degrees Celsius)
I more clearly labeled the temperature readings in both the main menu and the operating menu as “Current_Temp” to avoid confusion
-I more clearly labeled the target temperature readings in both the main menu and the operating menu as “Target_Temp” to avoid confusion
I more clearly labeled the motor reading in the main menu as “Motor_Status” to avoid confusion
I more clearly labeled the speed reading in the main menu as “Steps/s” to avoid confusion
I reset the default steps per second to 150 to make usage more convenient
I reset the default temperature to 210 degrees Celsius to make usage more convenient
I added notes to the .ino file to guide users when reconstructing the Upcycler
That was all for the code! I can get back to the good hardware stuff now!

An image of the Upcycler's OLED in its menu state

# Devlog 16
47min 55sec Logged

I finished updating the CAD files for my Upcycler project today!

I fixed the problem of the bodies’ legs always cracking when you screw in their screws too tight. I did that by creating notches for their caps to settle in. This should also keep the legs sturdy over long-term wear.

Another problem I’ve had for a while was the bodies not lining up in the assemblies for some reason. I found the root of that problem while improving the legs. The legs were actually slightly offset on the bodies on the x-axis for some reason. I was able to fix that easily when reattaching the legs. Redoing the base to fit this change was more difficult, but a bit of brute force did the trick ;)

I’ll be printing these new parts out now. After replacing the old ones, the Upcycler V3 will be done!

An image of the improved Short Leg

# Devlog 17
1h 2min Logged

I finished the Upcycler V3 today! YAY!

I started printing the new models I made yesterday this morning. There were only two parts (the main body and the short body) but they still took all day lol :p: .

I also had to fix my 3D printer in between the two prints because it started leaking filament out of its throat and the melted filament dripped onto the prints and left these weird brown streaks.

After the parts were finished I replaced the old parts with the new. That took a whole hour because all the smaller parts are built onto these two biggest parts, and I use very fine mechanical screws (which take a long time to install/remove). The new parts work really well, tho! They solved the old problem of the bases cracking when you screwed in their screws too tight.

Anyway, this is it! I tested the Upcycler V3 and it worked well! Just like its previous versions, you cut PET filament from 2L soda bottles into 7mm wide strips and feed them through the nozzle at 210 C at 150 steps/s.

Check out my GitHub repo if you want to build this yourself! YIPPIEEEEE!

An image of the completed Upcycler V3

# Devlog 18/Ship 1

I made a simple, affordable, and reliable take on the Petamentor. The Upcycler is a machine that turns plastic water bottles into 3D printing filament.

The process is as follows: smooth out any bumps and ridges on a 2L PET soda bottle using a heat gun. Use a bottle cutter to cut the bottle into a long 7mm wide strip. Cut down one end to a long point, and feed that point through the nozzle of the heat block.

Plug in the Upcycler's 12V 5A power supply and make any changes to the settings you would like in the menu. However, the default settings are what I would personally recommend from extensive testing. Test to make sure that the thermistor is operational by pressing your finger onto the heat block. There should be a change by a degree or two. Select the "motor status" option to put the Upcycler into Running mode. CAUTION: the Upcycler's heat block will get very hot! DO NOT TOUCH IT!!!!!

Wait until the heat block reaches 180 degrees C. Use a pair of pliers to begin pulling the plastic. You only need to pull until the plastic reaches the spool. Weave the plastic through one of the slots on the side of the spool. You may then leave the Upcycler to work on its own. Processing a full 2L soda bottle may take several hours.

Using the pulled PET in your 3D printer will require custom settings from normal PET. Since each 3D printer and brand of bottle will make the settings vary, I cannot give much advice. However, I can recommend making the nozzle hotter, as that seems to be a general theme for homemade PET.

Wow, that was quite the user's manual!

A challenge that I faced while making the Upcycler was the budget. I knew from the start that I wanted something for less than $100. The closest kits I could find online cost $150. However, as development went on, I managed to get the cost down to a mere $48.43! One big milestone I achieved in budgeting was the motor. The standard Petamentor uses a high-torque 12V 3RPM DC motor, with the cheapest one I could find being $10. However, using smart engineering, I made a diabolical 30:1 gear ratio, allowing me to use much cheaper 28BYJ-48 stepper motors (which only cost $3 each!) Additionally, using the DC motors would have forced me to buy expensive 12V power modules, which generally cost $15 dollars each. Avoiding that constraint, I could use simpler 12V 5A power supplies that cost only $8.

Something that I am proud of in the Upcycler is its dual-mode UI. While you use the Upcycler in its Running mode, you may hear periodical pauses in the motor's humming. Those pauses are caused when the Arduino Uno R3 switches from outputting commands to reading information from the thermistor. It does not have the capability to do both at the same time. Even worse was the joystick. With the constant updates the Arduino needs from the joystick to make navigation smooth, the motor would hardly run at all! To fix this problem, I cleverly separated the code into two parts: a menu mode and a Running mode. In the menu mode, all the Arduino does is read info. It can check the thermistor much faster than in the Running mode, and you can use the Joystick freely. However, when you switch over to Running mode, the joystick is mostly disabled. Instead, the Arduino can focus on outputs, like the motor and the MOSFET powering the heater. However, there are still occasional pauses to check the heat block's temperature (hence the periodical pauses). I also integrated the exit feature into that pause, so if you are holding the joystick down at the moment of the reading, you will exit back into menu mode. I am proud of this workaround I made in the code because I would have had to use a more powerful chip (or two Arduinos!) without it. I managed to fully capitalize on the power of a weak chip to fulfill my criteria.

Another image of the completed Upcycler V3

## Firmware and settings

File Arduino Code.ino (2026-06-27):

// Hi! This is the code to put in the Arduino UNO R3 for my Upcycler project! This is currently version 3.0, as of 6/24/2025. I hope you find my Upcycler helpful!
#include <math.h>
#include <Wire.h>
#include <Adafruit_GFX.h>
#include <Adafruit_SSD1306.h>
#define WIDTH 128
#define HEIGHT 64
Adafruit_SSD1306 display(WIDTH, HEIGHT, &Wire, -1);
#define JX A3
#define JY A2
#define JSW 4
#define MOSFET 5
#define IN1 8
#define IN2 9
#define IN3 10
#define IN4 11
#define THERMISTOR A0
#define SERIESRESISTOR 100000
#define THERMISTORNOMINAL 100000
#define TEMPERATURENOMINAL 25
#define BCOEFFICIENT 3950
int menuIndex = 0;
bool editing = false;
const int menuSize = 3;
bool motorEnabled = false;
float targetTemp = 210;
int stepsPerSecond = 150;
const float TEMP_OFFSET = 11.0;
float Kp = 5.2;
float Ki = 0.055;
float Kd = 14.0;
float integral = 0;
float lastError = 0;
unsigned long lastMoveTime = 0;
const int moveDelay = 180;
unsigned long lastStepTime = 0;
unsigned long stepInterval = 1000000 / 150;
int stepIndex = 0;
float smoothedTemp = 25.0;
unsigned long lastControlUpdate = 0;
int seq[8][4] = {
    {1,0,0,0},
    {1,1,0,0},
    {0,1,0,0},
    {0,1,1,0},
    {0,0,1,0},
    {0,0,1,1},
    {0,0,0,1},
    {1,0,0,1}
};
float readTemperature() {
    long total = 0;
    for (int i = 0; i < 10; i++) total += analogRead(THERMISTOR);
    float adc = total / 10.0;
    float resistance = SERIESRESISTOR / ((1023.0 / adc) - 1.0);
    float t = resistance / THERMISTORNOMINAL;
    t = log(t);
    t /= BCOEFFICIENT;
    t += 1.0 / (TEMPERATURENOMINAL + 273.15);
    t = 1.0 / t;
    t -= 273.15;
    return t;
}
void stepMotor() {
    digitalWrite(IN1, seq[stepIndex][0]);
    digitalWrite(IN2, seq[stepIndex][1]);
    digitalWrite(IN3, seq[stepIndex][2]);
    digitalWrite(IN4, seq[stepIndex][3]);
    stepIndex++;
    if (stepIndex >= 8) stepIndex = 0;
}
void setup() {
    pinMode(IN1, OUTPUT);
    pinMode(IN2, OUTPUT);
    pinMode(IN3, OUTPUT);
    pinMode(IN4, OUTPUT);
    pinMode(MOSFET, OUTPUT);
    analogWrite(MOSFET, 0);
    pinMode(JSW, INPUT_PULLUP);
    display.begin(SSD1306_SWITCHCAPVCC, 0x3C);
    display.setTextColor(SSD1306_WHITE);
    Serial.begin(115200);
}
void loop() {
    runMotor();
    if (motorEnabled) {
        lockedMode();
    } else {
        handleJoystick();
        runPID();
        drawMenu();
    }
}
void runMotor() {
    if (!motorEnabled) return;
    unsigned long now = micros();
    stepInterval = 1000000 / stepsPerSecond;
    if (now - lastStepTime >= stepInterval) {
        lastStepTime = now;
        stepMotor();
    }
}
void lockedMode() {
    unsigned long now = millis();
    if (now - lastControlUpdate > 500) {
        lastControlUpdate = now;
        runPID();
        if (digitalRead(JSW) == LOW) {
            delay(200);
            motorEnabled = false;
        }
        drawLockedScreen();
    }
}
void runPID() {
    float rawTemp = readTemperature();
    smoothedTemp = 0.85 * smoothedTemp + 0.15 * rawTemp;
    float controlTarget = targetTemp + TEMP_OFFSET;
    float error = controlTarget - smoothedTemp;
    if (abs(error) < 2) integral *= 0.98;
    else integral += error * 0.5;
    if (integral > 150) integral = 150;
    if (integral < -150) integral = -150;
    float derivative = error - lastError;
    lastError = error;
    float output = Kp * error + Ki * integral + Kd * derivative;
    int pwm = output;
    if (pwm < 0) pwm = 0;
    if (pwm > 255) pwm = 255;
    if (!motorEnabled) pwm = 0;
    analogWrite(MOSFET, pwm);
}
void handleJoystick() {
    int xVal = analogRead(JX);
    int yVal = analogRead(JY);
    unsigned long now = millis();
    if (!editing) {
        if (yVal < 400 && now - lastMoveTime > moveDelay) {
            menuIndex--;
            if (menuIndex < 0) menuIndex = menuSize - 1;
            lastMoveTime = now;
        } else if (yVal > 600 && now - lastMoveTime > moveDelay) {
            menuIndex++;
            if (menuIndex >= menuSize) menuIndex = 0;
            lastMoveTime = now;
        }
    } else {
        if (menuIndex == 1) {
            if (xVal > 600 && now - lastMoveTime > moveDelay) {
                targetTemp += 5;
                if (targetTemp > 240) targetTemp = 240;
                lastMoveTime = now;
            } else if (xVal < 400 && now - lastMoveTime > moveDelay) {
                targetTemp -= 5;
                if (targetTemp < 180) targetTemp = 180;
                lastMoveTime = now;
            }
        }
    }
    if (digitalRead(JSW) == LOW) {
        delay(200);
        if (menuIndex == 0 && !editing) {
            motorEnabled = !motorEnabled;
        } else {
            editing = !editing;
        }
    }
}
void drawMenu() {
    display.clearDisplay();
    display.setTextSize(2);
    display.setCursor(0, 0);
    display.print("UPCYCLER");
    display.setTextSize(1);
    display.println("v3.0");
    display.setTextSize(1);
    display.setCursor(0, 18);
    display.print("Current_Temp: ");
    display.print(smoothedTemp, 1);
    display.print("C");
    display.setCursor(0, 34);
    display.print(menuIndex == 0 ? "> " : "  ");
    display.print("Motor_Status: ");
    display.print(motorEnabled ? "ON" : "OFF");
    display.setCursor(0, 46);
    display.print(menuIndex == 1 ? "> " : "  ");
    display.print("Target_Temp: ");
    display.print((int)targetTemp);
    display.print("C");
    display.setCursor(0, 58);
    display.print(menuIndex == 2 ? "> " : "  ");
    display.print("Steps/s: ");
    display.println(stepsPerSecond);
    display.display();
}
void drawLockedScreen() {
    display.clearDisplay();
    display.setTextSize(2);
    display.setCursor(0, 0);
    display.println("RUNNING");
    display.setTextSize(1);
    display.setCursor(0, 20);
    display.print("Current_Temp: ");
    display.print(smoothedTemp, 1);
    display.print("C");
    display.setCursor(0, 35);
    display.print("Target_Temp: ");
    display.print(targetTemp);
    display.print("C");
    display.setCursor(0, 50);
    display.println("Hold to STOP");
    display.display();
}

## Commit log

2026-06-12 Create Parts to Print
2026-06-12 Add Arduino code for motor control and display
2026-06-12 Document progress on Upcycler project and geartrain design
    Added details about the geartrain design and adjustments made to the Upcycler project. Updated images to reflect the latest model changes.
2026-06-12 Add Devlog 5 entry with modeling updates
    Documented progress on modeling screws and assembly.
2026-06-12 Add Devlog 12 with MOSFET module update
    Updated assembly to include the MOSFET module instead of the relay. Added new images and details for Devlog 12.
2026-06-12 Add updated CAD assembly image to Journal.md
    Added an updated CAD assembly image to the journal.
2026-06-27 Update and rename Arduino Code to Arduino Code.ino
